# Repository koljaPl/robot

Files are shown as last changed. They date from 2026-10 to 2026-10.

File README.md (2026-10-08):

# robot - From Simulation to Reality: How does a robot learn?

## Implementierung und aktueller Stand

Die [vollständige Übergabe mit 19 Abschnitten](docs/HANDOFF.md) enthält recherchierte Teile, Preise/Links, mechanische Spezifikation, Verkabelung, vollständigen Code, Kalibrierung und Baufolge. [Prüfprotokoll](docs/VALIDATION.md), [CAD/Explosionszeichnung](cad/ASSEMBLY.md), [Druckanfrage](cad/QUOTE_REQUEST.md) und [Simulationsvideo](docs/validation/nominal.mp4) liegen ebenfalls bei.

**Hardware noch nicht zum Kauf freigegeben:** Der bekannte Betrag einschließlich Versand beträgt **90,32 €**. Für Druckteile, passende Hörner/Schrauben und einen ausreichend belastbaren Stromanschluss bleiben 9,68 €; diese Kosten sind noch unbekannt. Es wurde nichts bestellt oder an echter Hardware getestet. Das Modell und die Druckdateien sind vorläufig.

Die Simulation ist lauffähig: sechs Gelenke (Hüft-Pitch, Knie-Pitch, Knöchel-Roll je Bein), geschätzte Masse 208,4 g, 50-Hz-Steuerung und IMU-basierte Beobachtungen ohne erfundene Gelenkrückmeldung. Zwölf Tests bestanden. Ein PPO-Testlauf mit 10.240 Schritten und zehn Auswertungen zeigte 30 Sekunden Stehen, **keine alternierenden Schritte** und nur etwa 1–2 mm Vorwärtsbewegung. Das Gehziel ist noch nicht erreicht.

```bash
python3.12 -m venv .venv
source .venv/bin/activate
python -m pip install -r requirements.txt
python evaluate.py --episodes 1 --output runs/neutral
python train.py --steps 2048 --seed 0 --output runs/smoke
python evaluate.py --model runs/smoke/final_model.zip --episodes 5 --seed 1000
```

Ein geprüftes Testmodell liegt unter `docs/validation/smoke_checkpoint.zip`. Video:

```bash
MUJOCO_GL=egl python evaluate.py --model docs/validation/smoke_checkpoint.zip --episodes 1 --video --output runs/video
```

Die Hardware-Kommunikation ist als begrenztes Protokoll mit Watchdog/Arming und Pseudocode beschrieben; deploybare Firmware und automatische Hardware-Steuerung sind noch nicht implementiert.

## PPP-Woche: Robotik, ML und Simulation

## Thema
**Robotik, Machine Learning und Computersimulation**

**Leitfrage:**  
Wie kann ein Roboter eine Bewegung in einer Simulation lernen und das Gelernte danach auf einen echten Roboter übertragen?

## Teilthemen

**Kolja:**  
Reinforcement Learning – Wie kann ein Roboter durch Versuch und Irrtum lernen?

**Ilgar:**  
Sim-to-Real – Wie kann man eine in der Simulation gelernte Steuerung auf einen echten Roboter übertragen?

## Idee
Wir wählen verfügbare Bauteile, prüfen Preis und mechanischen Aufbau und bilden diesen Roboter in einer Physik-Simulation nach.
Dort soll er selbstständig lernen, sich vorwärts zu bewegen. Dafür bekommt er für gute Aktionen eine Belohnung (Reward).

Danach versuchen wir, das trainierte Modell auf einen echten Roboter zu übertragen.

Zusätzlich wollen wir testen, ob das Training besser funktioniert, wenn sich während des Trainings Dinge wie Reibung, Gewicht oder Motorstärke leicht verändern.

## Grober Plan

1. Aufgabe, verfügbare Teile und vollständigen Lieferpreis prüfen
2. Einen Motor, Stromversorgung, Controller und IMU testen und vermessen
3. Passende Druckteile bestätigen, Prototyp montieren und wiegen
4. Digitale Kopie aus diesen Messungen erstellen und prüfen
5. Reinforcement-Learning-Umgebung erstellen
6. erstes Modell trainieren
7. Training mit zufällig veränderten Bedingungen
8. Ergebnisse vergleichen
9. Modell auf echten Roboter übertragen
10. Simulation und Realität vergleichen
11. Präsentation und Dokumentation fertig machen

## Was wir messen wollen

- zurückgelegte Strecke
- Geschwindigkeit
- Anzahl der Stürze
- sichtbare Fußhebung und alternierende Schritte (Rutschen zählt nicht)
- eventuell Energieverbrauch
- Unterschied zwischen Simulation und echtem Roboter

## Aufgabenverteilung

**Kolja**
- Simulation
- Reinforcement Learning
- Training
- Auswertung der Trainingsdaten

**Ilgar**
- Aufbau des echten Roboters
- Elektronik und Motoren
- Kalibrierung
- Tests in der echten Welt

**Zusammen**
- Planung
- Sim-to-Real
- Experimente
- Vergleich der Ergebnisse
- Präsentation

## Technik

- Python
- MuJoCo
- Gymnasium
- Stable-Baselines3 / PPO
- Raspberry Pi Pico H, PCA9685 und MPU6050 für den echten Roboter

## Ziel

Am Ende wollen wir zeigen, wie ein Computer ohne vorprogrammierte Bewegungsabläufe selbst lernen kann und warum eine Simulation nie genau gleich wie die echte Welt ist.

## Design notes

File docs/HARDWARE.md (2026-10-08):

# Hardware interface and power — provisional, no tested firmware

The baseline is six Waveshare 15024 MG90S servos, Pico H, BerryBase 157066 PCA9685, Funduino MPU6050 module, and Mean Well GST40A05-P1J. Do not energize a complete robot until the connector, harness, servo current and fit gates in `procurement.json` pass. No purchases or hardware tests were performed.

## Power circuit

```mermaid
flowchart TD
  AC[Wall socket] --> Lead[Schuko–C13 lead]
  Lead --> PSU[Enclosed Mean Well 5 V / 5 A PSU]
  PSU --> Cut[Accessible 5 A rated DC disconnect — selection pending]
  Cut --> Bus[Short heavy copper positive and ground buses]
  Bus --> S[Six servo branches; bulk capacitor across bus]
  PC[Laptop USB-A] --> Pico[Pico H USB, logic only]
  Pico --> Logic[3.3 V PCA9685 logic and MPU6050]
  Pico --> PWM[PCA9685 six PWM signal outputs]
  PWM --> S
  Bus --> Ground[Single common ground connection to logic]
  Ground --> Pico
```

**Servo supply current bypasses the Pico, Dupont jumpers, breadboards, and the unverified PCA9685 power traces.** The selected PCA board generates pulses; it does not drive the motors electrically. Its chip's output-current specification concerns signals, not the servo V+ rail. [NXP datasheet](https://www.nxp.com/docs/en/data-sheet/PCA9685.pdf)

A helper prepares six 10 cm JR extensions as a power-injection harness. Keep the signal conductor connected between the male PCA-end connector and the female servo connector. Disconnect the power and return conductors from the PCA-end connector and join their **servo-side** ends to the positive and negative buses. Insulate all cut stubs and joints. Each servo still plugs into a replaceable extension. Add a short logic ground connection at the bus entry. Leave PCA V+ and its motor-power terminal unused. Verify continuity and connector polarity before any servo is attached. This wire preparation is part of the accepted helper job; the student assembles finished parts. The extensions' wire gauge and branch current rating remain unverified.

Use 0.75 mm² copper for buses no longer than 0.10 m each way. Resistance estimate at room temperature is `0.0175 × 0.20 / 0.75 = 0.0047 Ω`; 4.8 A would drop about 0.022 V there, **excluding PSU lead, connectors and individual servo leads**. A 2 m one-way tether of the same wire would drop about 0.45 V at 4.8 A and is unsuitable for a nominal 5 V rail. For the first 0.3 m trials use the PSU's existing lead, place the PSU near the floor test area, and route a slack loop with strain relief close to the torso COM. Several metres require a separately sourced thicker low-resistance cable and longer USB lead; these are not included in the certified-price subtotal.

Current assumptions, **not MG90S measurements**:

| State | Per servo hypothesis | Six-servo total |
|---|---:|---:|
| Loaded standing / slow movement average | 0.10–0.25 A | 0.6–1.5 A |
| Brief acceleration / near stall | 0.8 A | 4.8 A |

Pico, IMU and PWM logic draw from laptop USB, provisionally below 0.15 A combined. A 5 A PSU has only 0.2 A margin against the assumed six-servo peak. The selected servo has **no reliable product-specific current specification**: if measured transients exceed capacity, voltage drops below 4.8 V, or a connector becomes warm, stop and revise the budget/power design. A capacitor does not fix an undersized PSU. At 4.8 A, 1000 µF sustains only roughly 0.04 ms for a 0.2 V drop. It helps short transients, not sustained stalls.

Check loaded voltage at the farthest servo, including the factory PSU lead. The acceptable measured operating range is 4.8–6.0 V; do not assume a nominal 5 V label guarantees 4.8 V at every motor. Keep mains wiring entirely inside commercial leads and the enclosed PSU. [Selected PSU](https://www.berrybase.de/meanwell-schaltnetzteil-5v-dc-5-0a-mit-hohlstecker-5-5x2-1mm)

The required physical cutoff is an accessible **DC unplug connection rated for the full expected current**, near the operator. Its sourcing is still open. Disconnect it to remove servo power; the small downstream capacitor discharges briefly. A mains switch is a useful backup but has PSU hold-up delay. Disabling PWM or sending STOP cannot guarantee an analogue servo releases its last position, and is never equivalent to disconnecting power. Disarm before reconnecting servo power. No rail-voltage or per-servo current measurement is built in.

The €0.50 Goobay 76743 screw adaptor is a researched candidate with an **unknown current rating**, not a verified 5 A solution. The €1.80 BerryBase DCKSW cable is unavailable and also lacks a confirmed suitable DC rating. Neither is accepted to close the basket. [Adaptor](https://www.berrybase.de/dc-kupplung-fuer-hohlstecker-5-5x2-1mm-schraubmontage-terminal-block-2-pin), [switch cable](https://www.berrybase.de/dc-kabel-mit-schalter-5-5x2-1mm-stecker-5-5x2-1mm-buchse-35cm)

## Logic wiring

| Pico signal / physical pin | Connection |
|---|---|
| 3V3 OUT / 36 | PCA VCC and IMU VCC, both 3.3 V logic |
| GND / 38 | PCA GND, IMU GND and short connection to servo return bus |
| GP4 / 6 | I2C0 SDA, both boards |
| GP5 / 7 | I2C0 SCL, both boards |
| GP6 / 9 | PCA OE, 10 kΩ pull-up to 3.3 V |
| USB Micro B | USB data and Pico power |

The Pico never connects servo 5 V to VBUS, VSYS or 3V3. Use one short I2C bus at 400 kHz, PCA default address 0x40, IMU address 0x68 with AD0 grounded; scan first. Verify both modules' pull-ups go to **3.3 V**, not servo 5 V. Set MPU6050 ±16 g, ±2000°/s, approximately 44 Hz digital filtering and 200 Hz sample rate. Rotate the measured sensor axes into torso x-forward/y-left/z-up coordinates before passing samples to the shared estimator. [Pico pinout](https://datasheets.raspberrypi.com/pico/Pico-R3-A4-Pinout.pdf), [MPU6050 registers](https://invensense.tdk.com/wp-content/uploads/2015/02/MPU-6000-Register-Map1.pdf)

PCA channels 0–5: left hip, left knee, left ankle, right hip, right knee, right ankle. Set actual PWM frame frequency to 50 Hz and calibrate its oscillator; nominal PWM resolution is about 4.88 µs per tick. Configure OE-high outputs LOW. The board may have an onboard OE pull-down: remove/change it if necessary so the external pull-up actually disables outputs during Pico reset. Verify the power-up waveform before attaching horns. The selected servo's 3.3 V signal threshold is unknown and must pass a one-servo bench test. Do not assume every MG90S-labelled servo has identical electronics.

Helper soldering: any loose IMU/PCA headers, six signal output pins if not fitted, OE pull-up, capacitor and power-injection harness. A temperature-controlled iron, flux-core solder, cutters/stripper, heat-shrink and multimeter suffice. Borrow the school's equipment if possible; tools are excluded from the component budget. Solder/heat preparation happens away from attached servos and USB. No frame drilling, sawing, tapping or heat-set inserts are planned.

## Version 1 serial protocol

USB CDC, nominal serial baud 460800, ASCII newline packets, at most **192 bytes including newline**. No dynamically growing input buffer. Payload ends in `*HHHH\n`, CRC-16/CCITT with initial 0xFFFF (Python `binascii.crc_hqx`). SI units in Python; integer milliradians, millimetres/s² and milliradians/s on the wire. Use monotonic local timestamps modulo 2³² ms. USB baud is a descriptor setting, not the native CDC throughput limit.

| Payload before checksum | Purpose |
|---|---|
| `H,1,seq,pc_ms` | Hello/configuration query |
| `I,1,seq,mcu_ms,digest,cal_valid` | Hello response: lowercase 64-character SHA-256 digest and calibration validity 0/1 |
| `A,1,seq,pc_ms,1` | Explicit arm request |
| `A,1,seq,pc_ms,0` | Disarm request, always permitted |
| `C,1,seq,pc_ms,q0,q1,q2,q3,q4,q5` | Six validated target angles |
| `S,1,seq,pc_ms` | Stop: disable PWM and latch stop fault |
| `R,1,seq,pc_ms` | Clear faults only while disarmed and after their causes have been corrected; does not arm |
| `T,1,ack_seq,mcu_ms,status,q0,...,q5,ax,ay,az,gx,gy,gz` | Applied-target acknowledgement plus raw IMU sample, 200 Hz |

Status bit mask: 1 armed; 2 watchdog fault; 4 invalid command; 8 sensor/configuration fault; 16 stopped. Any fault is latched and disarms; rearming requires explicit fault clear after cause correction and a new handshake. Header sequence is uint16, time uint32; reject duplicates, stale packets and backward sequences with modulo comparison (`0 < delta < 32768`). More than 100 ms since a **valid fresh C command** disables PWM. Hello and telemetry do not refresh the command watchdog. PC monitors missing telemetry with its own 100 ms deadline. Neither clock is presumed synchronized. Use relative deltas and record receive times; handshake measures offset/round-trip latency.

Use one increasing PC sequence counter for all control packets. Only perform a new H handshake while disarmed. At H receipt, MCU records `pc_to_mcu_offset = mcu_receive_ms - pc_ms` modulo 2³². Convert later C timestamps with that offset, using signed wrap-safe differences; reject commands with inferred age above 80 ms or more than 20 ms in the future. PC checks handshake round-trip time is below 20 ms before requesting ARM. These provisional timing tolerances require bench measurement. A packet with a new sequence but old timestamp must not refresh the watchdog. Telemetry repeats the latest **applied C sequence**, so the PC permits repeated acknowledgements while independently requiring advancing MCU sample timestamps and rejecting duplicate/backward IMU samples.

`hardware_interface.py` implements bounded command encoding, CRC validation, telemetry parsing and per-servo calibrated pulse mapping. Command endpoints round inward to avoid quantized unsafe angles. `H/I/A/S/R` are protocol specifications, not implemented MCU handlers in this delivery. Digest is SHA-256 of the exact shared calibration/configuration file bytes agreed by PC and MCU; this file must include joint order, signs, angle limits, zero pulses, pulse gains, slew limit and IMU rotation/bias. Do not use the simulation-only XML hash as the hardware configuration digest. A receiver must validate exact packet kind, field count, integer range, CRC and version before any state change. Flush overlong input until newline, latch error, and keep outputs disabled. Never accept Python pickles, executable text, or unbounded JSON.

Applied targets describe the **post-validation, post-delay, post-rate-limiter commands** written to PWM. They are not measured shaft angles. Telemetry repeats the latest applied targets between 50 Hz updates. Do not label acknowledged angles “joint feedback.” Calibrate each channel's centre pulse, sign, µs/radian gain and safe pulse endpoints; there is no universal safe 500–2500 µs mapping.

## MCU and PC pseudocode

```text
BOOT:
  OE = HIGH; PWM outputs LOW; state = DISARMED
  load measured calibration; refuse ARM if absent or corrupt
  configure I2C, PCA 50 Hz, IMU 200 Hz; verify communication
  set applied targets to HOME but do not enable PWM

MAIN LOOP (nonblocking; hardware monotonic clock):
  parse bounded frames and CRC
  STOP/DISARM => OE HIGH; clear target queue; latch state as appropriate
  fresh valid COMMAND => check bounds; enqueue target; update watchdog
  ARM => only after explicit handshake, fresh HOME command, valid IMU,
         matching policy/configuration digest and cleared faults
  if armed and now - last_valid_command >= 100 ms:
      OE HIGH; state = WATCHDOG_FAULT; clear queue
  every 5 ms:
      read IMU; remove measured stationary biases; rotate into torso axes
      send timestamped T packet, applied targets, latest applied sequence, status
      sensor read failure/invalid sample => OE HIGH; latch fault
  every 20 ms if armed:
      accept pending command; apply measured command-delivery scheduling
      apply calibrated deadband and rate limit (initially <=3.6 degrees/tick)
      bound angles; map calibrated pulses; quantize to measured PCA ticks
      write six channels together; update applied targets/ack sequence

PC (initially hardware disconnected; no automatic ARM):
  load policy and matching physical/control/calibration configuration
  handshake, check version/order/calibration, initialize filter from rest IMU
  at each timestamped IMU sample:
      GravityEstimator.update(gyro, accel, measured_dt)
      check gyro/accel saturation, faults and freshness
  every 20 ms:
      frame = gravity(3), gyro/10(3), latest applied targets normalized(6),
              previous requested policy action(6)
      append to the same five-frame ObservationHistory
      policy predicts action; use action_to_target; send C frame
      remember requested action
  operator explicitly arms for a limited supervised trial
  fault, tilt >60 degrees, missing telemetry or Ctrl-C => send STOP;
      operator disconnects DC power and manually resets the robot
```

Initialize history with five copies of the measured resting frame, as in simulation. The simulator's initial 0.2 s settling interval does not replace a real startup check. Nominal command delay is a **provisional total PC-command to acknowledged-PWM delay** of 20 ms; at 50 Hz the random 20–40 ms delay often rounds to the next 40 ms tick. Do not add another guessed delay to the MCU until timings are measured. Servo shaft lag is represented separately by finite position-control dynamics. Timestamp comparisons need wrap handling and missed-tick rejection. This pseudocode requires implementation and electrical testing before hardware deployment.

Protect the USB lead and heavy power lead with a slack loop. Keep connector mass supported externally where possible. Cable force is not simulated, so record routing and direction in every physical trial. Never reset an RL episode by commanding an uncontrolled fallen robot back to HOME. Cut power, pick it up, inspect gears/brackets, then reinitialize.

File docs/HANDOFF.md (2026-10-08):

# School Biped S6 — hardware-first implementation handoff

Research checked 8 October 2026. Generated by `tools/build_handoff.py`; source files embedded below are the actual project files. **Status: runnable, locally tested simulation; provisional hardware design; procurement and manufacturing remain blocked.** Sourced claims, estimates, software results and unmeasured hardware are distinguished throughout.

## 1. Short design recommendation

Use six Waveshare 15024 MG90S servos in a small biped with **hip pitch, knee pitch and ankle roll on each leg**. Short 50 mm thighs/shins, broad 90 × 45 mm feet, laptop inference, Pico H, PCA9685 and an MPU6050 form a reasonable research baseline for slow stepping. Estimated assembled mass is **208.4 g**, with approximately **189 mm frame height** in the home pose. No arms or decorative head are required.

This is a prototype proposal, not a verified walking kit. The known delivered basket is **€90.32**, leaving **€9.68 for every unresolved item**. Finished prints, matched horns, fasteners and a suitably rated power connector are still unquoted/unconfirmed. The €100 constraint has **not** been met by a complete purchasable basket. Do not order the full robot or manufacture these interfaces yet. No component purchases or supplier messages were made.

The software can immediately run test training. Its provisional twin uses the proposed frame and exact selected product dimensions, plus explicitly estimated interfaces and dynamics. It is not a frozen twin of an assembled robot. A 10,240-step smoke run produced standing and approximately 1–2 mm of drift, **not walking**. The six-servo [Lynxmotion BRAT](https://wiki.lynxmotion.com/info/wiki/lynxmotion/view/ses-v1/ses-v1-robots/ses-v1-bipeds/brat/) is a mechanical precedent; it does not prove small-servo RL transfer.

## 2. Comparison of 6 DOF versus 8 DOF

| Design | Walking / stability | Cost, mass and power | RL / transfer / mechanics | Decision |
|---|---|---|---|---|
| A: each leg hip roll, hip pitch, knee pitch; 6 total | Lateral leg control, but both ankle axes fixed; foot orientation and landing constrained | Six servos €21, 73.2 g before frame; six unknown current loads | Few actions; fixed feet may require large lean and edge contact; easy frame, falls load hip gears | Compare only |
| B: A + ankle pitch; 8 total | Better sagittal foot alignment; no ankle roll; larger motion range | Servos €28, 97.6 g; **at least** €7 and 24.4 g extra plus brackets/wires/printing; assumed simultaneous peaks rise 4.8 → 6.4 A | More actions, failure points and calibration; extra freedom does not automatically help RL; proposed 5 A supply no longer covers the peak hypothesis | Upgrade requiring a new budget/power/frame design |
| Selected: hip pitch, knee pitch, ankle roll; 6 total | Direct lateral weight shift at the feet; broad soles help; coupled sagittal foot pitch limits step length | Six servos; same motor cost as A; short links reduce bending moments | Six controls and replaceable brackets; repeatable slow lean/lift/land sequence is plausible; no hip yaw or ankle pitch limits turning and uneven-ground performance | Baseline |

Eight joints cannot fit the present basket without further cost reductions: extra motors alone take the known subtotal to €97.32, before additional frame/power and the existing unknowns. Choose few joints to reduce calibration, wear and budget pressure. Neither configuration supplies true servo feedback or certified continuous torque. Stable walking remains an experiment.

## 3. Selected robot architecture

Joint order is **left hip, left knee, left ankle, right hip, right knee, right ankle**, everywhere. SI coordinates are **x forward, y left, z up**. Hips and knees rotate about local **+y**; ankle roll about **+x**. At zero angles, body axes match the parent. Positive pitch tips a downward link toward −x; positive ankle roll rotates the foot plane according to the right-hand rule. Physical right-hand servo mounting requires measured pulse signs; do not assume both legs share an electrical sign.

The torso contains the two hip servo housings, controller, PWM board and IMU. Each thigh carries its knee housing. Each shin carries no servo housing; each foot carries its ankle housing. This matches the proposed printed brackets and avoids double-counting actuator mass. Electronics are tied to the backplate with protected/insulated wiring; IMU mounting must be rigid. A short heavy power bus feeds servo branches separately from the logic.

The policy runs at **50 Hz** on the laptop. Pico processes the IMU at **200 Hz**, updates PCA pulse targets at 50 Hz and reports **post-limit command targets**, never measured shaft positions. MuJoCo runs at 500 Hz. A 200 Hz IMU on the 2 ms simulation grid alternates 4/6 ms intervals; the estimator uses the actual interval.

Actions are six normalized values in `[-1,1]`, mapped linearly to the JSON safe intervals. Home angles are `[-10,10,0,-10,10,0]°`; neutral action is therefore **not six zeros**. Each observation frame is estimated gravity direction (3), gyro divided by 10 rad/s (3), normalized applied command targets (6), previous requested actions (6). Five frames make **90 float32 observations**. The same complementary gravity filter uses raw accelerometer/gyro in simulation and the robot. Sensor axes/bias are calibrated before filtering; accelerometer blending is suppressed for large deviations from gravity. Translation, true attitude, true joint angles, velocity and contact are excluded from policy inputs. Five frames give roughly 80 ms of history; they cannot recover every unobserved servo error.

## 4. Servo comparison

These are product-specific claims, not interchangeable specifications for all similarly named servos. Prices include VAT; stock and variants must be checked at checkout. 1 kgf·cm = 0.09807 N·m.

| Exact product / source | Unit price / availability | Size; mass | Voltage; claimed stall torque | Claimed unloaded speed | Gear/control / assessment |
|---|---|---|---|---|---|
| [Waveshare 15286 SG90](https://www.welectron.com/Waveshare-15286-SG90-Servo_1) | €1.90; listing indicated about three months delivery | 22.8 × 12.2 × 28.5 mm; 10.5 g | 4.8–6 V; 2.0/2.2 kgf·cm | 0.09/0.08 s per 60° at 4.8/6 V | Plastic gears, position PWM; lower cost but gearbox/fall durability concerns; €9.60 saving for six does not establish the whole budget |
| **[Waveshare 15024 MG90S](https://www.welectron.com/Waveshare-15024-MG90S-Servo_1)** | **€3.50; shown in stock** | **22.8 × 12.2 × 28.5 mm; 12.2 g** | **4.8–6 V; 2.0/2.8 kgf·cm** | **0.11/0.09 s per 60° at 4.8/6 V** | Metal gears, position PWM; chosen for low price and replaceability, with selected-product dimensions |
| [MG90D at Rotorama](https://www.rotorama.de/product/mg90d) | €4.09; stock shown | 22.8 × 12.4 × 28.5 mm; 12 g | 4.8–6 V; 1.8/2.2 kgf·cm | Table says 0.10 and 0.08 s, both labelled 4.8 V; higher-voltage speed **unresolved** | Metal, digital position PWM; claimed 90° between 1000–2000 µs, horns included; not enough evidence of better repeatability to justify selecting it |
| [FEETECH FS90, Pololu data](https://www.pololu.com/product/2818/specs), [EU seller](https://eckstein-shop.de/feetech-fs90-1-5kg-analog-servo) | EU listing €3.55; availability/country messages ambiguous | 23.2 × 12.5 × 22 mm; 9 g | 4.8–6 V; 1.3/1.5 kgf·cm | 0.12/0.10 s per 60° | Plastic, analog PWM; 120° at 900–2100 µs, documented 3.3 V signals; weaker and different frame; **FS90R is continuous rotation and unsuitable** |

Selected listing also claims 180° travel and 5 µs deadband. Neither proves calibrated angular range, backlash or long-term repeatability. [Original TowerPro MG90S](https://towerpro.com.tw/product/mg90s-3/) has different mass/torque claims; those are not specifications for the Waveshare item. Very cheap servos can vary with load, voltage, temperature and wear. Metal gears do not guarantee low backlash. Expect per-servo calibration and replacements.

For all four, sustainable torque, lifetime and gear backlash are **unknown**. Current for the selected MG90S, SG90 and listed MG90D is **unknown**. Pololu measured approximately 600 mA stall and 200 mA no-load at 6 V for FS90, explicitly variable; its [manufacturer PDF](https://www.pololu.com/file/0J1435/FS90-specs.pdf) gives different current numbers. Do not transfer either current value to MG90S. No real torque/current measurements were performed.

Torque feasibility: `τ = m g d`. A 250 g mass at 20 mm offset requires `0.250 × 9.81 × 0.020 = 0.0491 N·m`; a rough 2× dynamic margin gives 0.0981 N·m. The selected seller's 4.8 V stall claim is 0.196 N·m. Stall torque is not a safe repeated-hold rating. The simulation starts with **0.08 N·m intermittent estimated force cap**; physical PWM servos have no programmable torque cap.

The actual 208.4 g proposed body distribution was evaluated by virtual work, holding the left foot fixed and allowing the right foot to be unloaded. Moments below are absolute magnitudes; this is a gravity calculation, not a loaded-servo test:

| Pose | Left hip | Left knee | Left ankle | 2× worst demand | Interpretation |
|---|---:|---:|---:|---:|---|
| Home, pretend single left support | 0.0013 | 0.0139 | 0.0695 N·m | 0.1390 N·m | COM is 34 mm to the side, outside 22.5 mm foot half-width; **not a feasible balanced single-support pose** |
| 15° lateral lean toward left | 0.0013 | 0.0134 | 0.0356 N·m | 0.0712 N·m | COM lateral offset 17.4 mm is inside the ideal support footprint; little measured margin yet |
| Lift right leg after leaning | 0.0039 | 0.0161 | 0.0337 N·m | 0.0675 N·m | Right knee gravity demand 0.0126 N·m; plausible slow-step starting pose |
| Deep stance bend, stress case | 0.0112 | 0.0494 | 0.0423 N·m | 0.0989 N·m | Exceeds provisional 0.08 N·m at 2× margin; do not treat every angle-limit pose as a safe loaded stance |

See [reproducible torque calculations](validation/torque_estimates.json) and `tools/torque_estimates.py`. Transfer weight before lifting; keep initial movements slow. Shock loads from falls are not covered by this static calculation.

## 5. Complete BOM with sourced prices and links

This is the complete **required-item register**, with unresolved costs explicitly retained. It is **not a complete purchasable basket**. Prices are checked listings, not saved checkout invoices. VAT and standard Germany shipping are included where priced. A free school helper is assumed for soldering/lead preparation; a paid charge must enter the budget. Laptop, measurement tools and ordinary screwdrivers are outside robot-part cost. No printer or battery is assumed.

| Category | Exact item / supplier source | Qty | Unit € | Line € | Selection / unresolved issue |
|---|---|---:|---:|---:|---|
| Motors | [Waveshare 15024 MG90S](https://www.welectron.com/Waveshare-15024-MG90S-Servo_1) — Welectron | 6 | 3.50 | 21.00 | VAT included, stock shown; horn/screw inclusion unverified |
| Electronics | [Raspberry Pi Pico H](https://www.berrybase.de/raspberry-pi-pico-rp2040-mikrocontroller-board-mit-headern) — BerryBase | 1 | 5.50 | 5.50 | Pre-soldered headers; USB Micro B |
| Electronics | [BerryBase 157066 PCA9685 board](https://www.berrybase.de/berrybase-16-kanal-pwm-servo-treiber-board-pca9685-i2c-12bit-1-6khz-3-3-5v) — BerryBase | 1 | 6.50 | 6.50 | One in stock; loose connectors in package. Use only signals/logic: power rail rating unknown |
| Sensors | [Funduino F23107397 MPU6050 module](https://funduinoshop.com/elektronische-module/sensoren/bewegungs-und-distanzsensoren/mpu-6050-modul-triaxial-beschleunigungssensor-gyroskop) — Funduino | 1 | 2.90 | 2.90 | Header soldering/board orientation to confirm |
| Power | [Mean Well GST40A05-P1J 5 V 5 A desktop PSU](https://www.berrybase.de/meanwell-schaltnetzteil-5v-dc-5-0a-mit-hohlstecker-5-5x2-1mm) — BerryBase | 1 | 14.90 | 14.90 | C14 inlet; centre-positive 5.5 x 2.1 mm; no mains lead in package |
| Power | [Goobay 68604 Schuko to C13, 1.5 m](https://www.berrybase.de/kaltgeraete-netzkabel-schutzkontakt-stecker-abgewinkelt-iec320-c13-buchse-schwarz) — BerryBase | 1 | 3.81 | 3.81 | Exact 1.5 m variant; 10 A AC rating |
| Wiring/connectors | [Official Raspberry Pi RPI-MUSB-1 USB data cable 1 m](https://www.berrybase.de/offizielles-raspberry-pi-micro-usb-kabel-rot-1-0m) — BerryBase | 1 | 1.80 | 1.80 | USB-A PC assumed; USB-C-only PC requires extra adapter, currently not priced |
| Wiring/connectors | [DUPK-40-FF-20, 40 female-female Dupont leads, 20 cm](https://www.berrybase.de/40pin-jumper-dupont-kabel-female-female-trennbar/laenge-0-20-m) — BerryBase | 1 | 1.80 | 1.80 | Logic/IMU only, AWG28; never main servo power |
| Wiring/connectors | [Funduino F23108007 JR-Futaba extension, 10 cm](https://funduinoshop.com/elektronische-module/elektromotoren-und-zubehoer/elektromotoren/servomotoren/jr-futaba-servo-verlaengerung-kabel-10cm-female/male) — Funduino | 6 | 1.42 | 8.52 | Helper prepares power-injection harness; branch current rating/gauge unverified |
| Wiring/connectors | [Donau E-175-16 violet copper wire 0.75 mm², 10 m roll](https://www.berrybase.de/donau-kupferschaltlitze-0-75-mm2-10m-lang-1-adrig-24x0-20mm-pvc-isoliert) — BerryBase | 1 | 5.50 | 5.50 | Only short power buses, <=10 cm each way; label positive/negative with shrink sleeve. Not a long tether |
| Power | [AiSHi ELK1M16VAWH 1000 µF 16 V capacitor](https://www.berrybase.de/elektrolytkondensator-1000-f-16v-1050c-1-radial-tht) — BerryBase | 1 | 0.29 | 0.29 | Polarity matters; actual tolerance ±20%, inconsistent page title ignored |
| Electronics | [MSW10K.25 10 kOhm axial resistor](https://www.berrybase.de/bauelemente/passive-bauelemente/widerstaende/) — BerryBase | 1 | 0.05 | 0.05 | OE pull-up; SKU price verified on category; exact detail URL not resolved |
| Wiring/connectors | [PINH-1X40P 40-pin 2.54 mm header](https://www.berrybase.de/stiftleiste-1x-40-polig-rm-2-54-gerade) — BerryBase | 1 | 0.60 | 0.60 | Helper cuts/solders signal and sensor headers as needed; Pico headers already fitted |
| Wiring/connectors | [McPower T1535561 heat-shrink, 100 pieces](https://www.berrybase.de/schrumpfschlauch-set-100-teilig-schwarz) — BerryBase | 1 | 1.90 | 1.90 | Insulate helper-soldered harness; mark polarity; helper supplies solder as workshop consumable |
| Fasteners | [McPower T1535501 cable ties, 100 x 2.5 mm, pack of 100](https://www.berrybase.de/kabelbinder-uv-bestaendig-nylon-100-stueck/farbe-transparent/masse-100x2-5mm) — BerryBase | 1 | 0.45 | 0.45 | 8 board mounts, 4 cable strain relief, 8 harness restraints; keep away from pinch points |
| Mechanical | [7 ready-finished PETG frames + 2 bonded TPU soles, VAT and German shipping](https://meltlab.de/preise) — Print service, quote pending | 1 | **pending** | **pending** | Exact STL upload quote unavailable; no printer/browser surface available. Not a price allowance |
| Mechanical | [6 matching horns + 6 servo shaft retaining screws](https://www.welectron.com/Waveshare-15024-MG90S-Servo_1) — Selected servo supplier; package confirmation pending | 1 | **pending** | **pending** | Required. Do not assume included; exact spline/horn pattern/shaft screw thread unknown |
| Fasteners | 12 M2 x 8 mm ear screws, 12 M2 nuts, 24 M2 washers; 12 horn-to-frame screws/washers matched to supplied horns — Print-service assembly kit quote pending | 1 | **pending** | **pending** | Dimensions/lengths provisional; supplier must include a matching kit and factory-clear holes. No drilling/tapping by assembler |
| Power | 5 A rated DC female 5.5 x 2.1 mm input pigtail/coupler and accessible disconnect, strain relief — Not selected: current-rated connector still unresolved | 1 | **pending** | **pending** | Goobay 76743 €0.50 not accepted as 5 A rated; rating unknown. Required input connection cannot be omitted |
| Shipping | [Welectron German DPD shipping](https://www.welectron.com/Shipping-cost) — Welectron | 1 | 4.95 | 4.95 | Basket under €49 free-shipping threshold |
| Shipping | [BerryBase German DHL shipping](https://www.berrybase.de/versand-und-zahlungsbedingungen) — BerryBase | 1 | 4.95 | 4.95 | Basket under €150 free-shipping threshold |
| Shipping | [Funduino German shipping](https://funduinoshop.com/versand-und-zahlungsbedingungen) — Funduino | 1 | 4.90 | 4.90 | One combined sensor/extensions order; separate first-servo order would add another shipping charge |

Selection rationale and alternatives: Pico H avoids header soldering and unnecessary Wi-Fi; a bare Pico might save board cost but adds soldering and needs a fresh price check. PCA9685 gives a common 50 Hz pulse source; Pico has enough PWM channels to replace it, but that changes this baseline and the firmware. MPU6050 is an inexpensive useful attitude/gyro source; no camera, lidar, encoder or foot switch is required. An IMU is strongly recommended because a command-only controller cannot detect body tipping. The enclosed Mean Well PSU avoids exposed mains wiring; a generic cheaper adapter is not accepted without a credible voltage/current rating and compliance documentation. Pre-soldered IMU/PWM alternatives could reduce helper work, but their delivered prices have not been established. Wires, resistor, header, capacitor, ties and shrink sleeve provide the required harness/OE/mounting functions; borrowing spare workshop parts changes actual cost only when confirmed.

The selected PCA board package lists loose connectors, so helper assembly is included as work, not assumed already soldered. Servo branches use six extensions prepared by the helper for power injection; branch gauge/current capability must be checked. No rail rating is assumed for PCA traces. Horn/screw inclusion is **not verified** and remains a required pending item.

Optional items: one spare MG90S costs €3.50 before any extra delivery; a slack safety line, thin protective mat and longer USB/heavier power tether remain unpriced optional additions. A USB-C-only laptop requires an adapter, which would become required. The baseline PSU lead/USB cable are approximately 1 m: initial short steps are possible near the supply, but a few-metre travel setup needs a separately priced tether. No complex overhead rig is mandatory.

## 6. Total cost and budget gate

| Budget element | Cost |
|---|---:|
| Known required products | **€75.52** |
| Welectron + BerryBase + Funduino standard shipping | **€14.80** |
| Known delivered subtotal | **€90.32** |
| Finished printing/soles, matched horn hardware, fasteners, rated DC connection | **Unknown** |
| Complete delivered total | **Not established** |
| Remaining under €100 for every unknown | **€9.68** |

The €50–75 target is not achieved by this basket: known products alone exceed €75, before shipping and all pending items. There is **no verified cheapest viable delivered configuration** under €100. The recommended configuration above is conditional on a passing quote and fit gate. An explicitly revised direct-Pico-PWM design could remove the €6.50 PCA board, bringing this known subtotal to €83.82 if all other costs stayed equal; printing/hardware remain unknown, so this is not a purchasable alternative or a silent substitution. Weaker servos have not been selected to disguise a shortfall.

If pending delivered costs sum to `U`, complete cost is `90.32 + U`; actual shortfall is `max(0, U − 9.68)`. No numeric shortfall can be truthfully reported before the quote. `tools/budget_gate.py` treats unpriced parts as pending, never zero; it exits 2 for incomplete, 1 for over budget and 0 only for a fully cleared basket. See [current machine-readable gate](budget_status.json).

The [Meltlab price/quotation page](https://meltlab.de/preise) and [Printfaktur](https://printfaktur.de/) provide quote routes. An exact quote was not obtained: no browser/upload surface is available in this environment, and no supplier was contacted. [Ready-to-review quotation brief](../cad/QUOTE_REQUEST.md) and [quote bundle](../cad/quote_bundle.zip) include exact prototype files. A headline per-part printing price or an allowance is not a quotation. Resolve horn/ear fit before sending a manufacturing order. If the delivered quote breaks €100, stop procurement and revise explicitly.

## 7. Mechanical design and assembly

`physical_spec.json` is the authoritative physical ledger. `build_model.py` mirrors right-side components and computes aggregate mass/COM/full inertia, assigning each servo, frame, PCB, fastener allowance and wire allowance **exactly once**. Rigid-body inertias are solid CAD estimates for PETG frames and uniform-box estimates for other components, combined using the parallel-axis theorem. They are not measured inertias. The hanging tether is excluded; its disturbance must later be measured.

| Body | Parent | Joint / axis | Origin in parent (mm) | Limits (°) | Mass (g) | COM local (mm) |
|---|---|---|---|---|---:|---|
| torso | world | root / floating | 0.000, 0.000, 154.240 | free | 81.89 | -7.350, 0.000, -8.997 |
| left_thigh | torso | left_hip / 0.000, 1.000, 0.000 | 0.000, 34.000, -30.000 | [-35, 35] | 18.97 | 0.000, -9.434, -42.970 |
| left_shin | left_thigh | left_knee / 0.000, 1.000, 0.000 | 0.000, 0.000, -50.000 | [-10, 60] | 7.72 | 1.432, 1.714, -22.688 |
| left_foot | left_shin | left_ankle / 1.000, 0.000, 0.000 | 0.000, 0.000, -50.000 | [-20, 20] | 36.58 | -1.919, 0.000, -15.367 |
| right_thigh | torso | right_hip / 0.000, 1.000, 0.000 | 0.000, -34.000, -30.000 | [-35, 35] | 18.97 | 0.000, 9.434, -42.970 |
| right_shin | right_thigh | right_knee / 0.000, 1.000, 0.000 | 0.000, 0.000, -50.000 | [-10, 60] | 7.72 | 1.432, -1.714, -22.688 |
| right_foot | right_shin | right_ankle / 1.000, 0.000, 0.000 | 0.000, 0.000, -50.000 | [-20, 20] | 36.58 | -1.919, -0.000, -15.367 |

Torso envelope is 40 × 82 × 66 mm. Each inter-joint leg segment is 50 mm. Feet are 90 × 45 × 3 mm PETG plus 1 mm TPU, local centre x = +6 mm, z = −22.5 mm for the plate and −24.5 mm for the sole. Ankle-to-floor distance is 25 mm when flat. Servo dimensions refer to the seller's overall case envelope; shaft, ears, spline, horn holes and lead exit are **unmeasured**. These unresolved features prevent manufacturing release.

| Body | Component (mass assigned once) | Dimensions xyz (mm) | Mass (g) | COM local xyz (mm) |
|---|---|---|---:|---|
| torso | torso_frame | 32.000, 82.000, 88.750 | 21.49 | -16.308, -0.000, -5.438 |
| torso | pico_h | 6.000, 51.000, 21.000 | 4.00 | -14.500, 0.000, 23.000 |
| torso | pca9685 | 9.000, 62.500, 25.400 | 9.00 | -13.000, 0.000, -2.000 |
| torso | imu | 4.000, 16.000, 20.000 | 3.00 | -25.500, 0.000, 18.000 |
| torso | torso_wires_fasteners | 30.000, 70.000, 40.000 | 20.00 | 0.000, 0.000, 5.000 |
| torso | left_hip_servo | 12.200, 28.500, 22.800 | 12.20 | 0.000, 19.750, -34.750 |
| torso | right_hip_servo | 12.200, 28.500, 22.800 | 12.20 | 0.000, -19.750, -34.750 |
| left_thigh | left_thigh_frame | 24.000, 13.500, 87.750 | 5.27 | 0.000, -0.974, -24.526 |
| left_thigh | left_knee_servo | 12.200, 28.500, 22.800 | 12.20 | 0.000, -14.250, -54.750 |
| left_thigh | left_thigh_joint_fasteners | 20.000, 12.000, 12.000 | 1.50 | 0.000, 0.000, -12.000 |
| left_shin | left_shin_frame | 24.000, 24.000, 78.000 | 6.22 | 1.777, 2.128, -25.264 |
| left_shin | left_shin_joint_fasteners | 20.000, 12.000, 12.000 | 1.50 | 0.000, 0.000, -12.000 |
| left_foot | left_foot_frame | 90.000, 45.000, 38.250 | 18.02 | 4.134, 0.000, -20.373 |
| left_foot | left_sole | 90.000, 45.000, 1.000 | 4.86 | 6.000, 0.000, -24.500 |
| left_foot | left_ankle_servo | 28.500, 12.200, 22.800 | 12.20 | -14.250, 0.000, -4.750 |
| left_foot | left_foot_joint_fasteners | 20.000, 12.000, 12.000 | 1.50 | 0.000, 0.000, -12.000 |
| right_thigh | right_thigh_frame | 24.000, 13.500, 87.750 | 5.27 | 0.000, 0.974, -24.526 |
| right_thigh | right_knee_servo | 12.200, 28.500, 22.800 | 12.20 | 0.000, 14.250, -54.750 |
| right_thigh | right_thigh_joint_fasteners | 20.000, 12.000, 12.000 | 1.50 | 0.000, 0.000, -12.000 |
| right_shin | right_shin_frame | 24.000, 24.000, 78.000 | 6.22 | 1.777, -2.128, -25.264 |
| right_shin | right_shin_joint_fasteners | 20.000, 12.000, 12.000 | 1.50 | 0.000, 0.000, -12.000 |
| right_foot | right_foot_frame | 90.000, 45.000, 38.250 | 18.02 | 4.134, -0.000, -20.373 |
| right_foot | right_sole | 90.000, 45.000, 1.000 | 4.86 | 6.000, 0.000, -24.500 |
| right_foot | right_ankle_servo | 28.500, 12.200, 22.800 | 12.20 | -14.250, 0.000, -4.750 |
| right_foot | right_foot_joint_fasteners | 20.000, 12.000, 12.000 | 1.50 | 0.000, 0.000, -12.000 |

Component dimensions are approximate envelopes, not every detailed printed surface. Frames use solid PETG density 1270 kg/m³, TPU estimate 1200 kg/m³. Actual infill and finished printing change mass. Fastener/wire masses are estimates; servo mass is a seller claim. Aggregate full inertias are:

| Body | Ixx, Iyy, Izz, Ixy, Ixz, Iyz (kg·m²) |
|---|---|
| torso | 8.105528e-05, 5.228549e-05, 4.646465e-05, 2.541099e-21, 8.152129e-06, 0 |
| left_thigh | 1.075608e-05, 9.509007e-06, 2.306097e-06, -1.321365e-23, 9.846622e-24, -2.552041e-06 |
| left_shin | 3.771568e-06, 3.870593e-06, 4.366762e-07, 1.069363e-08, 2.608766e-07, -1.717284e-07 |
| left_foot | 7.376615e-06, 2.141873e-05, 2.153521e-05, -9.25926e-23, 2.911645e-06, 1.500083e-22 |
| right_thigh | 1.075608e-05, 9.509007e-06, 2.306097e-06, 1.321365e-23, 9.846622e-24, 2.552041e-06 |
| right_shin | 3.771568e-06, 3.870593e-06, 4.366762e-07, -1.069363e-08, 2.608766e-07, 1.717284e-07 |
| right_foot | 7.376615e-06, 2.141873e-05, 2.153521e-05, 9.25926e-23, 2.911645e-06, -1.500083e-22 |

Editable CAD is [cad/build_frame.py](../cad/build_frame.py), producing seven named frame STLs and two sole STLs in `cad/stl/`. All nine meshes are watertight and each frame is one connected solid. `quotation_plate.stl` is a convenience visualization of the seven frames; **do not order it in addition to those frames**. No external proprietary CAD program is needed to edit the Python dimensions. [Exploded view](../cad/exploded.png) shows assembly relationships. [Assembly instructions and fastener counts](../cad/ASSEMBLY.md) cover six joints and electronics mounting.

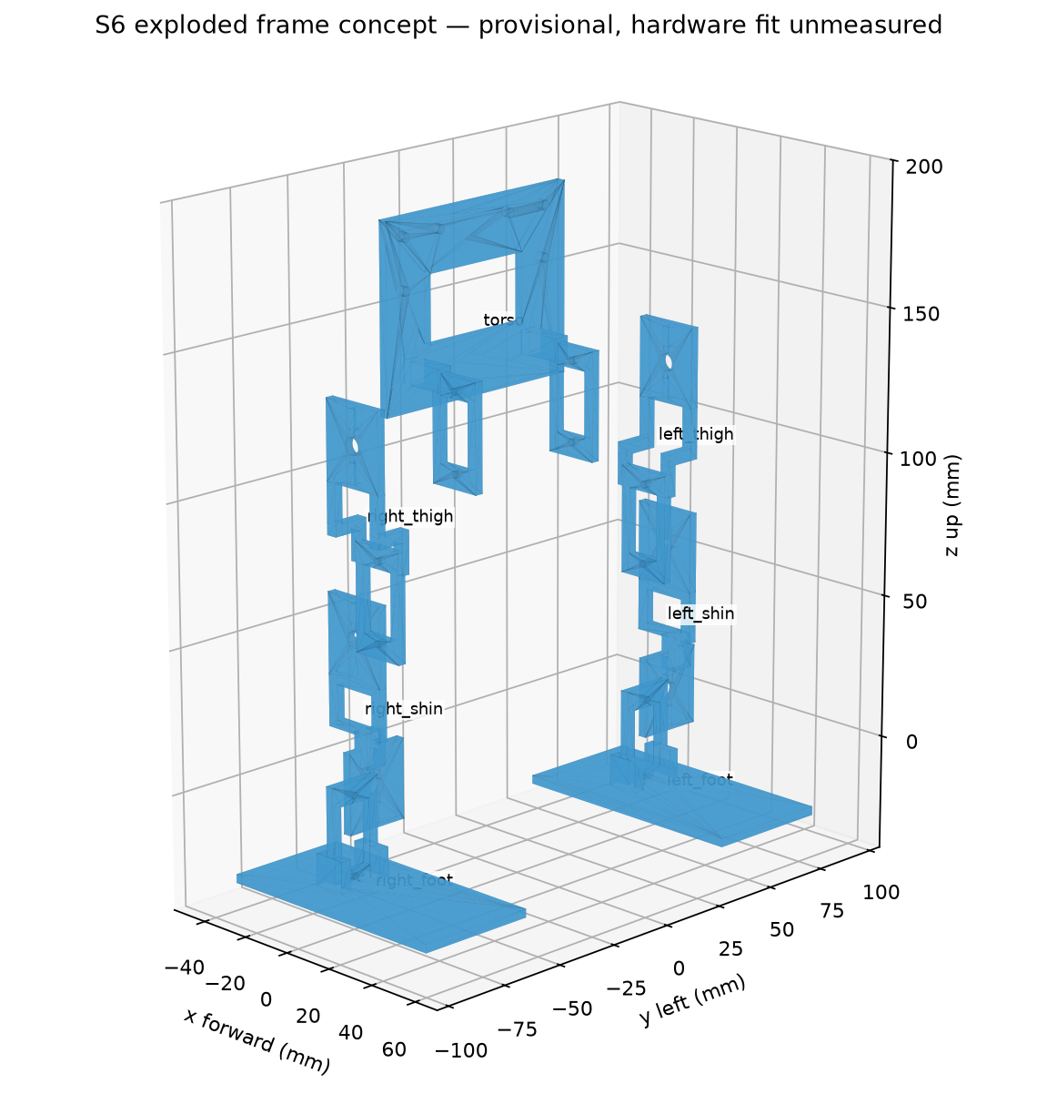
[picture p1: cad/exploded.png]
Exploded prototype frame; interface fit is not manufacturing-approved


Prepared parts must arrive with usable holes and no cutting/drilling/tapping/heat-set inserts. Provisional quantities are 12 M2 × 8 ear screws, 12 nuts, 24 washers, 12 matched horn-to-frame screws/washers, six horn shaft screws and six horns. Exact horn screw thread and mounting lengths must be confirmed with the actual package. The service must include any sole bonding/finishing; its price is pending. Printed walls are nominally 3 mm; preferred PETG frame and compliant replaceable TPU soles. A finite mesh audit checked 55 poses for frame/frame and assigned-case/frame intersections; it does not certify horn fit, cable clearance, strength, all continuous poses or every neighboring component.

The full physical ledger is included here so copying the runnable sources also supplies their required JSON:

```json
{
  "name": "School Biped S6",
  "status": "PROVISIONAL: budget, printed fit and hardware calibration not approved",
  "units": "m, kg, rad, s",
  "coordinates": "x forward, y left, z up; local body axes match parent at zero joint angle",
  "home_joint_angles_deg": [-10, 10, 0, -10, 10, 0],
  "servo": {
    "model": "Waveshare 15024 MG90S",
    "mass": 0.0122,
    "housing_dimensions": [
      0.0228,
      0.0122,
      0.0285
    ],
    "shaft_offset_along_case_length": 0.00475,
    "shaft_to_case_center_axial": 0.01425,
    "mounting_hole_spacing": 0.028,
    "mounting_hole_diameter": 0.0022,
    "status": "housing size and mass are seller claims; shaft/ear/horn dimensions are estimates requiring measurement"
  },
  "geometry": {
    "hip_half_spacing": 0.034,
    "hip_z": -0.03,
    "thigh_length": 0.05,
    "shin_length": 0.05,
    "foot_dimensions": [
      0.09,
      0.045,
      0.003
    ],
    "foot_center": [
      0.006,
      0,
      -0.0225
    ],
    "sole_thickness": 0.001,
    "ankle_to_floor": 0.025,
    "torso_dimensions": [
      0.04,
      0.082,
      0.066
    ]
  },
  "bodies": [
    {
      "name": "torso",
      "parent": "world",
      "position": [
        0,
        0,
        0.154240388
      ],
      "joint": "root",
      "axis": null,
      "limits_deg": null,
      "components": [
        {
          "name": "torso_frame",
          "mass": 0.021486247742229223,
          "dimensions": [
            0.032,
            0.082,
            0.08875
          ],
          "com": [
            -0.016308210070435095,
            -5.215214943911107e-19,
            -0.0054384916759348196
          ],
          "inertia_tensor": [
            [
              2.6309016723560255e-05,
              2.703988807846125e-21,
              2.1653112995251776e-06
            ],
            [
              2.703988807846125e-21,
              1.3253368557151762e-05,
              3.4107973696966715e-22
            ],
            [
              2.1653112995251776e-06,
              3.4107973696966715e-22,
              1.578588698727872e-05
            ]
          ],
          "material": "solid PETG estimate, 1270 kg/m\u00b3",
          "evidence": "generated CAD; actual infill/printed density must be weighed"
        },
        {
          "name": "pico_h",
          "mass": 0.004,
          "dimensions": [
            0.006,
            0.051,
            0.021
          ],
          "com": [
            -0.0145,
            0,
            0.023
          ],
          "material": "PCB and headers",
          "evidence": "estimate"
        },
        {
          "name": "pca9685",
          "mass": 0.009,
          "dimensions": [
            0.009,
            0.0625,
            0.0254
          ],
          "com": [
            -0.013,
            0,
            -0.002
          ],
          "material": "PCB and connectors",
          "evidence": "seller claim mass; height estimate"
        },
        {
          "name": "imu",
          "mass": 0.003,
          "dimensions": [
            0.004,
            0.016,
            0.02
          ],
          "com": [
            -0.0255,
            0,
            0.018
          ],
          "material": "PCB",
          "evidence": "estimate"
        },
        {
          "name": "torso_wires_fasteners",
          "mass": 0.02,
          "dimensions": [
            0.03,
            0.07,
            0.04
          ],
          "com": [
            0,
            0,
            0.005
          ],
          "material": "copper, plastic, steel",
          "evidence": "estimate includes six added 10 cm extensions, short heavy power wire, capacitor, pullup, board mounting ties and torso hardware; excludes suspended tether"
        },
        {
          "name": "left_hip_servo",
          "mass": 0.0122,
          "dimensions": [
            0.0122,
            0.0285,
            0.0228
          ],
          "com": [
            0,
            0.01975,
            -0.03475
          ],
          "material": "servo composite",
          "evidence": "seller mass, estimated uniform inertia"
        },
        {
          "name": "right_hip_servo",
          "mass": 0.0122,
          "dimensions": [
            0.0122,
            0.0285,
            0.0228
          ],
          "com": [
            0,
            -0.01975,
            -0.03475
          ],
          "material": "servo composite",
          "evidence": "seller mass, estimated uniform inertia"
        }
      ]
    },
    {
      "name": "left_thigh",
      "parent": "torso",
      "position": [
        0,
        0.034,
        -0.03
      ],
      "joint": "left_hip",
      "axis": [
        0,
        1,
        0
      ],
      "limits_deg": [
        -35,
        35
      ],
      "components": [
        {
          "name": "left_thigh_frame",
          "mass": 0.005273029560391083,
          "dimensions": [
            0.024,
            0.013500000000000002,
            0.08775
          ],
          "com": [
            2.6563334945902374e-19,
            -0.0009738150793376264,
            -0.02452563897898925
          ],
          "inertia_tensor": [
            [
              3.6463630740464687e-06,
              -1.3640154818355183e-24,
              3.5681746524361245e-23
            ],
            [
              -1.3640154818355183e-24,
              3.83564073707392e-06,
              -5.988303056018393e-07
            ],
            [
              3.5681746524361245e-23,
              -5.988303056018393e-07,
              4.6710755114091395e-07
            ]
          ],
          "material": "solid PETG estimate, 1270 kg/m\u00b3",
          "evidence": "generated CAD; actual infill/printed density must be weighed"
        },
        {
          "name": "left_knee_servo",
          "mass": 0.0122,
          "dimensions": [
            0.0122,
            0.0285,
            0.0228
          ],
          "com": [
            0,
            -0.01425,
            -0.05475
          ],
          "material": "servo composite",
          "evidence": "seller mass, estimated inertia"
        },
        {
          "name": "left_thigh_joint_fasteners",
          "mass": 0.0015,
          "dimensions": [
            0.02,
            0.012,
            0.012
          ],
          "com": [
            0,
            0,
            -0.012
          ],
          "material": "steel and plastic horns",
          "evidence": "estimate; weigh installed fasteners/horn"
        }
      ]
    },
    {
      "name": "left_shin",
      "parent": "left_thigh",
      "position": [
        0,
        0,
        -0.05
      ],
      "joint": "left_knee",
      "axis": [
        0,
        1,
        0
      ],
      "limits_deg": [
        -10,
        60
      ],
      "components": [
        {
          "name": "left_shin_frame",
          "mass": 0.006223103503190493,
          "dimensions": [
            0.024,
            0.024,
            0.078
          ],
          "com": [
            0.001777148714462294,
            0.002127532309995988,
            -0.025264417900762635
          ],
          "inertia_tensor": [
            [
              3.517439052233832e-06,
              1.526352745623322e-08,
              2.3238492246555624e-07
            ],
            [
              1.526352745623322e-08,
              3.5861170810492066e-06,
              -2.0583750953748297e-07
            ],
            [
              2.3238492246555624e-07,
              -2.0583750953748297e-07,
              3.5938805714611084e-07
            ]
          ],
          "material": "solid PETG estimate, 1270 kg/m\u00b3",
          "evidence": "generated CAD; actual infill/printed density must be weighed"
        },
        {
          "name": "left_shin_joint_fasteners",
          "mass": 0.0015,
          "dimensions": [
            0.02,
            0.012,
            0.012
          ],
          "com": [
            0,
            0,
            -0.012
          ],
          "material": "steel and plastic horns",
          "evidence": "estimate; weigh installed fasteners/horn"
        }
      ]
    },
    {
      "name": "left_foot",
      "parent": "left_shin",
      "position": [
        0,
        0,
        -0.05
      ],
      "joint": "left_ankle",
      "axis": [
        1,
        0,
        0
      ],
      "limits_deg": [
        -20,
        20
      ],
      "components": [
        {
          "name": "left_foot_frame",
          "mass": 0.018016309759572663,
          "dimensions": [
            0.09,
            0.045,
            0.03825
          ],
          "com": [
            0.004134161361397353,
            1.943645122968221e-20,
            -0.02037258709585519
          ],
          "inertia_tensor": [
            [
              3.5912674486333607e-06,
              -9.047277336272573e-23,
              4.2675158262628113e-07
            ],
            [
              -9.047277336272573e-23,
              1.1641060651440434e-05,
              1.4825539214630055e-22
            ],
            [
              4.2675158262628113e-07,
              1.4825539214630055e-22,
              1.356399711276919e-05
            ]
          ],
          "material": "solid PETG estimate, 1270 kg/m\u00b3",
          "evidence": "generated CAD; actual infill/printed density must be weighed"
        },
        {
          "name": "left_sole",
          "mass": 0.00486,
          "dimensions": [
            0.09,
            0.045,
            0.001
          ],
          "com": [
            0.006,
            0,
            -0.0245
          ],
          "material": "solid TPU 95A, density estimate 1200 kg/m\u00b3",
          "evidence": "estimate; includes adhesive uncertainty, weigh actual sole"
        },
        {
          "name": "left_ankle_servo",
          "mass": 0.0122,
          "dimensions": [
            0.0285,
            0.0122,
            0.0228
          ],
          "com": [
            -0.01425,
            0,
            -0.00475
          ],
          "material": "servo composite",
          "evidence": "seller mass, estimated inertia"
        },
        {
          "name": "left_foot_joint_fasteners",
          "mass": 0.0015,
          "dimensions": [
            0.02,
            0.012,
            0.012
          ],
          "com": [
            0,
            0,
            -0.012
          ],
          "material": "steel and plastic horns",
          "evidence": "estimate; weigh installed fasteners/horn"
        }
      ]
    },
    {
      "name": "right_thigh",
      "mirror_of": "left_thigh",
      "parent": "torso",
      "position": [
        0,
        -0.034,
        -0.03
      ],
      "joint": "right_hip",
      "axis": [
        0,
        1,
        0
      ],
      "limits_deg": [
        -35,
        35
      ]
    },
    {
      "name": "right_shin",
      "mirror_of": "left_shin",
      "parent": "right_thigh",
      "position": [
        0,
        0,
        -0.05
      ],
      "joint": "right_knee",
      "axis": [
        0,
        1,
        0
      ],
      "limits_deg": [
        -10,
        60
      ]
    },
    {
      "name": "right_foot",
      "mirror_of": "left_foot",
      "parent": "right_shin",
      "position": [
        0,
        0,
        -0.05
      ],
      "joint": "right_ankle",
      "axis": [
        1,
        0,
        0
      ],
      "limits_deg": [
        -20,
        20
      ]
    }
  ]
}
```

## 8. Wiring, power and hardware interface

### Hardware interface and power — provisional, no tested firmware

The baseline is six Waveshare 15024 MG90S servos, Pico H, BerryBase 157066 PCA9685, Funduino MPU6050 module, and Mean Well GST40A05-P1J. Do not energize a complete robot until the connector, harness, servo current and fit gates in `procurement.json` pass. No purchases or hardware tests were performed.

#### Power circuit

```mermaid
flowchart TD
  AC[Wall socket] --> Lead[Schuko–C13 lead]
  Lead --> PSU[Enclosed Mean Well 5 V / 5 A PSU]
  PSU --> Cut[Accessible 5 A rated DC disconnect — selection pending]
  Cut --> Bus[Short heavy copper positive and ground buses]
  Bus --> S[Six servo branches; bulk capacitor across bus]
  PC[Laptop USB-A] --> Pico[Pico H USB, logic only]
  Pico --> Logic[3.3 V PCA9685 logic and MPU6050]
  Pico --> PWM[PCA9685 six PWM signal outputs]
  PWM --> S
  Bus --> Ground[Single common ground connection to logic]
  Ground --> Pico
```

**Servo supply current bypasses the Pico, Dupont jumpers, breadboards, and the unverified PCA9685 power traces.** The selected PCA board generates pulses; it does not drive the motors electrically. Its chip's output-current specification concerns signals, not the servo V+ rail. [NXP datasheet](https://www.nxp.com/docs/en/data-sheet/PCA9685.pdf)

A helper prepares six 10 cm JR extensions as a power-injection harness. Keep the signal conductor connected between the male PCA-end connector and the female servo connector. Disconnect the power and return conductors from the PCA-end connector and join their **servo-side** ends to the positive and negative buses. Insulate all cut stubs and joints. Each servo still plugs into a replaceable extension. Add a short logic ground connection at the bus entry. Leave PCA V+ and its motor-power terminal unused. Verify continuity and connector polarity before any servo is attached. This wire preparation is part of the accepted helper job; the student assembles finished parts. The extensions' wire gauge and branch current rating remain unverified.

Use 0.75 mm² copper for buses no longer than 0.10 m each way. Resistance estimate at room temperature is `0.0175 × 0.20 / 0.75 = 0.0047 Ω`; 4.8 A would drop about 0.022 V there, **excluding PSU lead, connectors and individual servo leads**. A 2 m one-way tether of the same wire would drop about 0.45 V at 4.8 A and is unsuitable for a nominal 5 V rail. For the first 0.3 m trials use the PSU's existing lead, place the PSU near the floor test area, and route a slack loop with strain relief close to the torso COM. Several metres require a separately sourced thicker low-resistance cable and longer USB lead; these are not included in the certified-price subtotal.

Current assumptions, **not MG90S measurements**:

| State | Per servo hypothesis | Six-servo total |
|---|---:|---:|
| Loaded standing / slow movement average | 0.10–0.25 A | 0.6–1.5 A |
| Brief acceleration / near stall | 0.8 A | 4.8 A |

Pico, IMU and PWM logic draw from laptop USB, provisionally below 0.15 A combined. A 5 A PSU has only 0.2 A margin against the assumed six-servo peak. The selected servo has **no reliable product-specific current specification**: if measured transients exceed capacity, voltage drops below 4.8 V, or a connector becomes warm, stop and revise the budget/power design. A capacitor does not fix an undersized PSU. At 4.8 A, 1000 µF sustains only roughly 0.04 ms for a 0.2 V drop. It helps short transients, not sustained stalls.

Check loaded voltage at the farthest servo, including the factory PSU lead. The acceptable measured operating range is 4.8–6.0 V; do not assume a nominal 5 V label guarantees 4.8 V at every motor. Keep mains wiring entirely inside commercial leads and the enclosed PSU. [Selected PSU](https://www.berrybase.de/meanwell-schaltnetzteil-5v-dc-5-0a-mit-hohlstecker-5-5x2-1mm)

The required physical cutoff is an accessible **DC unplug connection rated for the full expected current**, near the operator. Its sourcing is still open. Disconnect it to remove servo power; the small downstream capacitor discharges briefly. A mains switch is a useful backup but has PSU hold-up delay. Disabling PWM or sending STOP cannot guarantee an analogue servo releases its last position, and is never equivalent to disconnecting power. Disarm before reconnecting servo power. No rail-voltage or per-servo current measurement is built in.

The €0.50 Goobay 76743 screw adaptor is a researched candidate with an **unknown current rating**, not a verified 5 A solution. The €1.80 BerryBase DCKSW cable is unavailable and also lacks a confirmed suitable DC rating. Neither is accepted to close the basket. [Adaptor](https://www.berrybase.de/dc-kupplung-fuer-hohlstecker-5-5x2-1mm-schraubmontage-terminal-block-2-pin), [switch cable](https://www.berrybase.de/dc-kabel-mit-schalter-5-5x2-1mm-stecker-5-5x2-1mm-buchse-35cm)

#### Logic wiring

| Pico signal / physical pin | Connection |
|---|---|
| 3V3 OUT / 36 | PCA VCC and IMU VCC, both 3.3 V logic |
| GND / 38 | PCA GND, IMU GND and short connection to servo return bus |
| GP4 / 6 | I2C0 SDA, both boards |
| GP5 / 7 | I2C0 SCL, both boards |
| GP6 / 9 | PCA OE, 10 kΩ pull-up to 3.3 V |
| USB Micro B | USB data and Pico power |

The Pico never connects servo 5 V to VBUS, VSYS or 3V3. Use one short I2C bus at 400 kHz, PCA default address 0x40, IMU address 0x68 with AD0 grounded; scan first. Verify both modules' pull-ups go to **3.3 V**, not servo 5 V. Set MPU6050 ±16 g, ±2000°/s, approximately 44 Hz digital filtering and 200 Hz sample rate. Rotate the measured sensor axes into torso x-forward/y-left/z-up coordinates before passing samples to the shared estimator. [Pico pinout](https://datasheets.raspberrypi.com/pico/Pico-R3-A4-Pinout.pdf), [MPU6050 registers](https://invensense.tdk.com/wp-content/uploads/2015/02/MPU-6000-Register-Map1.pdf)

PCA channels 0–5: left hip, left knee, left ankle, right hip, right knee, right ankle. Set actual PWM frame frequency to 50 Hz and calibrate its oscillator; nominal PWM resolution is about 4.88 µs per tick. Configure OE-high outputs LOW. The board may have an onboard OE pull-down: remove/change it if necessary so the external pull-up actually disables outputs during Pico reset. Verify the power-up waveform before attaching horns. The selected servo's 3.3 V signal threshold is unknown and must pass a one-servo bench test. Do not assume every MG90S-labelled servo has identical electronics.

Helper soldering: any loose IMU/PCA headers, six signal output pins if not fitted, OE pull-up, capacitor and power-injection harness. A temperature-controlled iron, flux-core solder, cutters/stripper, heat-shrink and multimeter suffice. Borrow the school's equipment if possible; tools are excluded from the component budget. Solder/heat preparation happens away from attached servos and USB. No frame drilling, sawing, tapping or heat-set inserts are planned.

#### Version 1 serial protocol

USB CDC, nominal serial baud 460800, ASCII newline packets, at most **192 bytes including newline**. No dynamically growing input buffer. Payload ends in `*HHHH\n`, CRC-16/CCITT with initial 0xFFFF (Python `binascii.crc_hqx`). SI units in Python; integer milliradians, millimetres/s² and milliradians/s on the wire. Use monotonic local timestamps modulo 2³² ms. USB baud is a descriptor setting, not the native CDC throughput limit.

| Payload before checksum | Purpose |
|---|---|
| `H,1,seq,pc_ms` | Hello/configuration query |
| `I,1,seq,mcu_ms,digest,cal_valid` | Hello response: lowercase 64-character SHA-256 digest and calibration validity 0/1 |
| `A,1,seq,pc_ms,1` | Explicit arm request |
| `A,1,seq,pc_ms,0` | Disarm request, always permitted |
| `C,1,seq,pc_ms,q0,q1,q2,q3,q4,q5` | Six validated target angles |
| `S,1,seq,pc_ms` | Stop: disable PWM and latch stop fault |
| `R,1,seq,pc_ms` | Clear faults only while disarmed and after their causes have been corrected; does not arm |
| `T,1,ack_seq,mcu_ms,status,q0,...,q5,ax,ay,az,gx,gy,gz` | Applied-target acknowledgement plus raw IMU sample, 200 Hz |

Status bit mask: 1 armed; 2 watchdog fault; 4 invalid command; 8 sensor/configuration fault; 16 stopped. Any fault is latched and disarms; rearming requires explicit fault clear after cause correction and a new handshake. Header sequence is uint16, time uint32; reject duplicates, stale packets and backward sequences with modulo comparison (`0 < delta < 32768`). More than 100 ms since a **valid fresh C command** disables PWM. Hello and telemetry do not refresh the command watchdog. PC monitors missing telemetry with its own 100 ms deadline. Neither clock is presumed synchronized. Use relative deltas and record receive times; handshake measures offset/round-trip latency.

Use one increasing PC sequence counter for all control packets. Only perform a new H handshake while disarmed. At H receipt, MCU records `pc_to_mcu_offset = mcu_receive_ms - pc_ms` modulo 2³². Convert later C timestamps with that offset, using signed wrap-safe differences; reject commands with inferred age above 80 ms or more than 20 ms in the future. PC checks handshake round-trip time is below 20 ms before requesting ARM. These provisional timing tolerances require bench measurement. A packet with a new sequence but old timestamp must not refresh the watchdog. Telemetry repeats the latest **applied C sequence**, so the PC permits repeated acknowledgements while independently requiring advancing MCU sample timestamps and rejecting duplicate/backward IMU samples.

`hardware_interface.py` implements bounded command encoding, CRC validation, telemetry parsing and per-servo calibrated pulse mapping. Command endpoints round inward to avoid quantized unsafe angles. `H/I/A/S/R` are protocol specifications, not implemented MCU handlers in this delivery. Digest is SHA-256 of the exact shared calibration/configuration file bytes agreed by PC and MCU; this file must include joint order, signs, angle limits, zero pulses, pulse gains, slew limit and IMU rotation/bias. Do not use the simulation-only XML hash as the hardware configuration digest. A receiver must validate exact packet kind, field count, integer range, CRC and version before any state change. Flush overlong input until newline, latch error, and keep outputs disabled. Never accept Python pickles, executable text, or unbounded JSON.

Applied targets describe the **post-validation, post-delay, post-rate-limiter commands** written to PWM. They are not measured shaft angles. Telemetry repeats the latest applied targets between 50 Hz updates. Do not label acknowledged angles “joint feedback.” Calibrate each channel's centre pulse, sign, µs/radian gain and safe pulse endpoints; there is no universal safe 500–2500 µs mapping.

#### MCU and PC pseudocode

```text
BOOT:
  OE = HIGH; PWM outputs LOW; state = DISARMED
  load measured calibration; refuse ARM if absent or corrupt
  configure I2C, PCA 50 Hz, IMU 200 Hz; verify communication
  set applied targets to HOME but do not enable PWM

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

PC (initially hardware disconnected; no automatic ARM):
  load policy and matching physical/control/calibration configuration
  handshake, check version/order/calibration, initialize filter from rest IMU
  at each timestamped IMU sample:
      GravityEstimator.update(gyro, accel, measured_dt)
      check gyro/accel saturation, faults and freshness
  every 20 ms:
      frame = gravity(3), gyro/10(3), latest applied targets normalized(6),
              previous requested policy action(6)
      append to the same five-frame ObservationHistory
      policy predicts action; use action_to_target; send C frame
      remember requested action
  operator explicitly arms for a limited supervised trial
  fault, tilt >60 degrees, missing telemetry or Ctrl-C => send STOP;
      operator disconnects DC power and manually resets the robot
```

Initialize history with five copies of the measured resting frame, as in simulation. The simulator's initial 0.2 s settling interval does not replace a real startup check. Nominal command delay is a **provisional total PC-command to acknowledged-PWM delay** of 20 ms; at 50 Hz the random 20–40 ms delay often rounds to the next 40 ms tick. Do not add another guessed delay to the MCU until timings are measured. Servo shaft lag is represented separately by finite position-control dynamics. Timestamp comparisons need wrap handling and missed-tick rejection. This pseudocode requires implementation and electrical testing before hardware deployment.

Protect the USB lead and heavy power lead with a slack loop. Keep connector mass supported externally where possible. Cable force is not simulated, so record routing and direction in every physical trial. Never reset an RL episode by commanding an uncontrolled fallen robot back to HOME. Cut power, pick it up, inspect gears/brackets, then reinitialize.

The helper needs a temperature-controlled soldering iron, solder, cutters/stripper and borrowed multimeter; these are tools and excluded from part cost. No equipment price was verified because helper use is assumed. The exact tasks are header/terminal assembly where supplied loose, sensor headers, OE pull-up adjustment if needed, and insulated direct power-injection harness joints. The student receives a ready-made harness and performs screw/plug assembly. Never bypass the power-connection rating gate just to avoid a small solder job.

## 9. MuJoCo and control parameter table

| Parameter | Starting value | Provenance / limitation |
|---|---|---|
| Total modeled mass | 0.208431 kg | Design ledger, not weighed hardware |
| Physics / integrator | 0.002 s; implicitfast | Numerical choice, locally compiled |
| Gravity | 0, 0, −9.81 m/s² | Indoor Earth approximation |
| Hip / knee / ankle limits | [−35,35] / [−10,60] / [−20,20]° | Software-safe hypotheses, calibrate actual range |
| Position kp / velocity kv | 0.9 N·m/rad / 0.012 N·m·s/rad | Estimated internal-servo response |
| Peak simulated actuator force | ±0.08 N·m | Estimated intermittent envelope; physical servo cannot enforce this setting |
| Torque-speed envelope | Available drive torque falls linearly toward seller unloaded speed | Simple DC-like estimate; braking torque retained, backdrive not hard speed clipped |
| Unloaded shaft speed reference | 60° / 0.11 s = 545°/s at 4.8 V | Selected seller claim, measure at actual 5 V/load |
| Command slew | 180°/s, at most 3.6° per 20 ms update | Target trajectory limit; **not a measured shaft-speed limit** |
| Command delay | 20 ms nominal; 20–40 ms DR | Estimate; delayed commands applied on 50 Hz ticks |
| Target deadband | 0.5° | Command hysteresis surrogate; not true gear backlash |
| Joint damping / friction loss / armature | 0.002 N·m·s/rad / 0.001 N·m / 5e−6 kg·m² | Estimated passive gearbox properties |
| Contact friction | 0.8 sliding, 0.005 torsional, 0.0001 rolling | Ground/TPU contact estimates; MuJoCo torsional/rolling coefficients have different units from sliding |
| Foot contact | Flat plate plus 1 mm sole box | Simple primitive, whole-foot clearance used for evaluation |
| Gyro / acceleration noise | 0.006 rad/s / 0.04 m/s² standard deviation | Conservative hypotheses, not measured MPU6050 noise |
| Gravity filter | 0.5 s blending time; 0.8–1.2 g acceptance window | Shared preprocessing choice, sensitive to sustained acceleration |

Position actuators implement bounded `kp(target − angle) − kv velocity`. The environment adds command queue latency, post-delay target slew, hysteresis and a direction-dependent torque-speed envelope. Joint motion remains dynamic. True actuator force limits exist in simulation only; hobby PWM hardware has no current/torque telemetry or programmable torque protection. Software angle/rate limits reduce risk but cannot prevent damage during stalls/falls. Model choice follows the [MuJoCo XML actuator reference](https://mujoco.readthedocs.io/en/latest/XMLreference.html).

Reward each 20 ms step is `dt × [10 clip(vx, −0.05, 0.06) + 0.2 upright − 0.5 abs(vy) − 0.0001 mean(action_rate²)]`, minus 2 on a fall. Capped forward progress discourages explosive speed; upright rewards standing; lateral motion discourages drift; command-rate penalty discourages abrupt actions. This is a **smoothness proxy, not measured electrical energy**. Ground-truth simulation motion is permitted for rewards/metrics, never policy observations. The simple reward admits standing as a local optimum; observed smoke results demonstrate that limitation.

Fall means root height below 60% of home height, tilt beyond 60°, or non-foot floor contact. A fall terminates; 30 s without a fall truncates. Training reset has a 0.2 s settling period excluded from reported episode duration. Physical reset is manual. Evaluation counts a lifted step only after landing, following **at least 40 ms continuous whole-foot clearance ≥3 mm with opposite-foot contact**. Alternating qualifying landings are counted separately. Success requires ≥0.3 m travel, no fall, at least two qualifying steps on each side and three alternations within 30 s. Sliding, toe pivots and hops without opposite-foot support do not meet this metric.

## 10. Full `robot.xml`

Save this as `robot.xml` beside the Python files and supplied `cad/stl/` directory. Meshes are visual only; primitive geometry handles contact. `build_model.py` regenerates XML from the ledger.

```xml
<!-- Generated from physical_spec.json; provisional hardware model. -->
<mujoco model="SchoolBipedS6_provisional">
  <compiler angle="radian" autolimits="true" inertiafromgeom="false" />
  <option timestep="0.002" gravity="0 0 -9.81" integrator="implicitfast" iterations="60" />
  <visual>
    <global offwidth="960" offheight="720" />
    <map znear="0.002" />
  </visual>
  <default>
    <joint limited="true" damping="0.002" armature="0.000005" frictionloss="0.001" />
    <geom condim="3" friction="0.8 0.005 0.0001" solref="0.008 1" solimp="0.9 0.95 0.001" />
    <position kp="0.9" kv="0.012" forcelimited="true" forcerange="-0.08 0.08" ctrllimited="true" />
  </default>
  <asset>
    <mesh name="torso_mesh" file="cad/stl/torso.stl" scale="0.001 0.001 0.001" />
    <mesh name="left_thigh_mesh" file="cad/stl/left_thigh.stl" scale="0.001 0.001 0.001" />
    <mesh name="left_shin_mesh" file="cad/stl/left_shin.stl" scale="0.001 0.001 0.001" />
    <mesh name="left_foot_mesh" file="cad/stl/left_foot.stl" scale="0.001 0.001 0.001" />
    <mesh name="right_thigh_mesh" file="cad/stl/right_thigh.stl" scale="0.001 0.001 0.001" />
    <mesh name="right_shin_mesh" file="cad/stl/right_shin.stl" scale="0.001 0.001 0.001" />
    <mesh name="right_foot_mesh" file="cad/stl/right_foot.stl" scale="0.001 0.001 0.001" />
  </asset>
  <worldbody>
    <light pos="0 -1 2" dir="0 0 -1" diffuse="0.8 0.8 0.8" />
    <geom name="floor" type="plane" size="3 3 0.05" rgba="0.87 0.88 0.90 1" />
    <body name="torso" pos="0 0 0.154240388">
      <geom name="torso_visual" type="mesh" mesh="torso_mesh" contype="0" conaffinity="0" group="2" rgba="0.12 0.55 0.83 1" />
      <inertial mass="0.08188624774" pos="-0.007350467977 0 -0.008997271212" fullinertia="8.105527885e-05 5.228548807e-05 4.64646527e-05 2.541098842e-21 8.152129337e-06 0" />
      <freejoint name="root" />
      <geom name="torso_collision" type="box" pos="0 0 0.01" size="0.02 0.041 0.025" rgba="0.10 0.45 0.8 0.8" />
      <site name="imu_site" pos="-0.0255 0 0.018" size="0.003" rgba="1 0.7 0 1" />
      <camera name="overview" pos="0.42 -0.5 0.24" xyaxes="0.766 0.643 0 -0.26 0.31 0.916" />
      <geom name="left_hip_servo_case" type="box" pos="0 0.01975 -0.03475" size="0.0061 0.01425 0.0114" rgba="0.15 0.15 0.17 1" />
      <geom name="right_hip_servo_case" type="box" pos="0 -0.01975 -0.03475" size="0.0061 0.01425 0.0114" rgba="0.15 0.15 0.17 1" />
      <body name="left_thigh" pos="0 0.034 -0.03">
        <geom name="left_thigh_visual" type="mesh" mesh="left_thigh_mesh" contype="0" conaffinity="0" group="2" rgba="0.12 0.55 0.83 1" />
        <inertial mass="0.01897302956" pos="7.38254531e-20 -0.009433651865 -0.04297017599" fullinertia="1.075607705e-05 9.509006643e-06 2.306096954e-06 -1.321364545e-23 9.846621791e-24 -2.552040829e-06" />
        <joint name="left_hip" type="hinge" axis="0 1 0" range="-0.6108652382 0.6108652382" />
        <geom name="left_thigh_link" type="capsule" fromto="0 0 -0.006 0 0 -0.044" size="0.006" rgba="0.12 0.55 0.83 1" />
        <geom name="left_knee_servo_case" type="box" pos="0 -0.01425 -0.05475" size="0.0061 0.01425 0.0114" rgba="0.15 0.15 0.17 1" />
        <body name="left_shin" pos="0 0 -0.05">
          <geom name="left_shin_visual" type="mesh" mesh="left_shin_mesh" contype="0" conaffinity="0" group="2" rgba="0.12 0.55 0.83 1" />
          <inertial mass="0.007723103503" pos="0.001431986556 0.001714317795 -0.0226881703" fullinertia="3.771568488e-06 3.870592897e-06 4.366762365e-07 1.069363096e-08 2.608766246e-07 -1.717283681e-07" />
          <joint name="left_knee" type="hinge" axis="0 1 0" range="-0.1745329252 1.047197551" />
          <geom name="left_shin_link" type="capsule" fromto="0 0 -0.006 0 0 -0.044" size="0.006" rgba="0.12 0.55 0.83 1" />
          <body name="left_foot" pos="0 0 -0.05">
            <geom name="left_foot_visual" type="mesh" mesh="left_foot_mesh" contype="0" conaffinity="0" group="2" rgba="0.12 0.55 0.83 1" />
            <inertial mass="0.03657630976" pos="-0.001919484737 9.573768603e-21 -0.0153667454" fullinertia="7.376615256e-06 2.141873222e-05 2.153521221e-05 -9.259259754e-23 2.911645236e-06 1.500083034e-22" />
            <joint name="left_ankle" type="hinge" axis="1 0 0" range="-0.3490658504 0.3490658504" />
            <geom name="left_foot_plate" type="box" pos="0.006 0 -0.0225" size="0.045 0.0225 0.0015" rgba="0.08 0.36 0.65 1" />
            <geom name="left_foot_sole" type="box" pos="0.006 0 -0.0245" size="0.045 0.0225 0.0005" rgba="0.15 0.15 0.15 1" />
            <site name="left_foot_sole_center" pos="0.006 0 -0.025" size="0.001" />
            <geom name="left_ankle_servo_case" type="box" pos="-0.01425 0 -0.00475" size="0.01425 0.0061 0.0114" rgba="0.15 0.15 0.17 1" />
          </body>
        </body>
      </body>
      <body name="right_thigh" pos="0 -0.034 -0.03">
        <geom name="right_thigh_visual" type="mesh" mesh="right_thigh_mesh" contype="0" conaffinity="0" group="2" rgba="0.12 0.55 0.83 1" />
        <inertial mass="0.01897302956" pos="7.38254531e-20 0.009433651865 -0.04297017599" fullinertia="1.075607705e-05 9.509006643e-06 2.306096954e-06 1.321364545e-23 9.846621791e-24 2.552040829e-06" />
        <joint name="right_hip" type="hinge" axis="0 1 0" range="-0.6108652382 0.6108652382" />
        <geom name="right_thigh_link" type="capsule" fromto="0 0 -0.006 0 0 -0.044" size="0.006" rgba="0.12 0.55 0.83 1" />
        <geom name="right_knee_servo_case" type="box" pos="0 0.01425 -0.05475" size="0.0061 0.01425 0.0114" rgba="0.15 0.15 0.17 1" />
        <body name="right_shin" pos="0 0 -0.05">
          <geom name="right_shin_visual" type="mesh" mesh="right_shin_mesh" contype="0" conaffinity="0" group="2" rgba="0.12 0.55 0.83 1" />
          <inertial mass="0.007723103503" pos="0.001431986556 -0.001714317795 -0.0226881703" fullinertia="3.771568488e-06 3.870592897e-06 4.366762365e-07 -1.069363096e-08 2.608766246e-07 1.717283681e-07" />
          <joint name="right_knee" type="hinge" axis="0 1 0" range="-0.1745329252 1.047197551" />
          <geom name="right_shin_link" type="capsule" fromto="0 0 -0.006 0 0 -0.044" size="0.006" rgba="0.12 0.55 0.83 1" />
          <body name="right_foot" pos="0 0 -0.05">
            <geom name="right_foot_visual" type="mesh" mesh="right_foot_mesh" contype="0" conaffinity="0" group="2" rgba="0.12 0.55 0.83 1" />
            <inertial mass="0.03657630976" pos="-0.001919484737 -9.573768603e-21 -0.0153667454" fullinertia="7.376615256e-06 2.141873222e-05 2.153521221e-05 9.259259754e-23 2.911645236e-06 -1.500083034e-22" />
            <joint name="right_ankle" type="hinge" axis="1 0 0" range="-0.3490658504 0.3490658504" />
            <geom name="right_foot_plate" type="box" pos="0.006 0 -0.0225" size="0.045 0.0225 0.0015" rgba="0.08 0.36 0.65 1" />
            <geom name="right_foot_sole" type="box" pos="0.006 0 -0.0245" size="0.045 0.0225 0.0005" rgba="0.15 0.15 0.15 1" />
            <site name="right_foot_sole_center" pos="0.006 0 -0.025" size="0.001" />
            <geom name="right_ankle_servo_case" type="box" pos="-0.01425 0 -0.00475" size="0.01425 0.0061 0.0114" rgba="0.15 0.15 0.17 1" />
          </body>
        </body>
      </body>
    </body>
  </worldbody>
  <actuator>
    <position name="left_hip_servo" joint="left_hip" ctrlrange="-0.6108652382 0.6108652382" />
    <position name="left_knee_servo" joint="left_knee" ctrlrange="-0.1745329252 1.047197551" />
    <position name="left_ankle_servo" joint="left_ankle" ctrlrange="-0.3490658504 0.3490658504" />
    <position name="right_hip_servo" joint="right_hip" ctrlrange="-0.6108652382 0.6108652382" />
    <position name="right_knee_servo" joint="right_knee" ctrlrange="-0.1745329252 1.047197551" />
    <position name="right_ankle_servo" joint="right_ankle" ctrlrange="-0.3490658504 0.3490658504" />
  </actuator>
  <sensor>
    <gyro name="imu_gyro" site="imu_site" />
    <accelerometer name="imu_accel" site="imu_site" />
  </sensor>
  <keyframe>
    <key name="home" qpos="0 0 0.154240388 1 0 0 0 -0.1745329252 0.1745329252 0 -0.1745329252 0.1745329252 0" ctrl="-0.1745329252 0.1745329252 0 -0.1745329252 0.1745329252 0" />
  </keyframe>
</mujoco>
```
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

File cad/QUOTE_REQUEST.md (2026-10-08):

# Quotation brief — not submitted and not an actual quotation

Please price the supplied **seven named PETG frame STLs once each**, plus **two named TPU sole STLs once each**. Ignore `quotation_plate.stl` for quantities: it duplicates the seven frames and is only a geometric grouping.

PETG: 0.2 mm layers, 3 perimeters, nominal 25% infill, stiff joint walls. TPU 95A: 90×45×1 mm soles, bonded to their feet with adhesive included. Supply parts cleaned, supports removed, holes clear for assembly with screws; the student has no drill/printer/taps. Please include German VAT, shipment, all finishing and a matched fastener kit. See `ASSEMBLY.md` for provisional fastener quantities. Please confirm layer orientation, dimensional tolerance and the mounting interfaces against a sample of the selected Waveshare 15024 MG90S and its actual supplied horns before manufacture.

The CAD is currently a **quotation/fit prototype**, not a manufacturing release. Servo shaft/ear/horn measurements must be supplied before final printing. Cost changes after those fit changes require a revised quote. No purchase authorization is implied by requesting a price.

Automatic service candidates researched: [Meltlab](https://meltlab.de/preise) and [Printfaktur](https://printfaktur.de/). No automatic upload/browser was available in this session, so no price was obtained. The remaining budget is only **€9.68 for printing, all unresolved fasteners/horns, and the current-rated power connection together**, using the current sourced basket. This number is a budget constraint, never a printing quotation. School lab/donated manufacturing could change cost, but is not assumed.

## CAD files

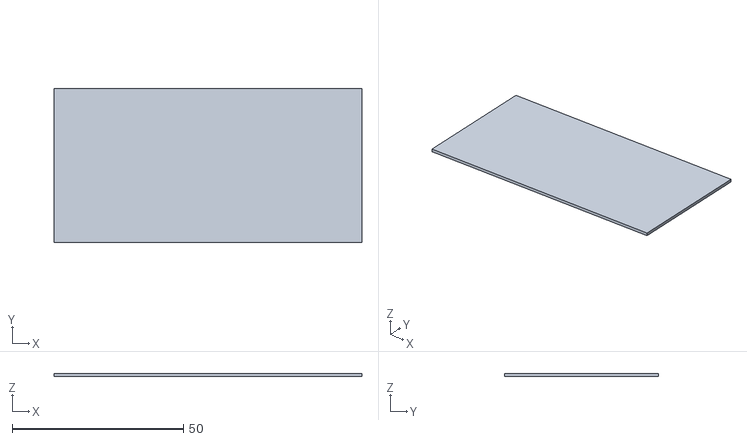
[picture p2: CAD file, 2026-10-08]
cad/stl/left_sole.stl
90.0 x 45.0 x 1.00

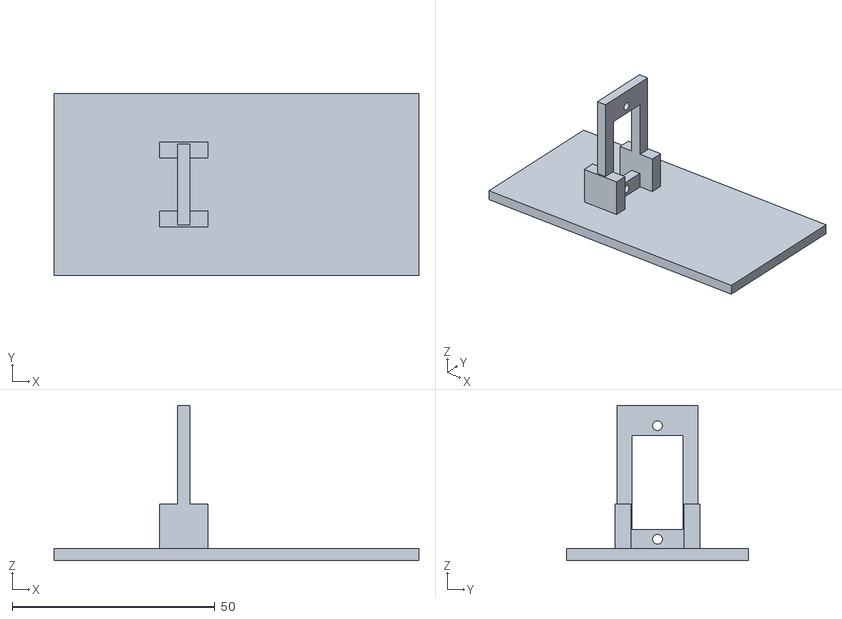
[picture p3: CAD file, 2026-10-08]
cad/stl/right_foot.stl
90.0 x 45.0 x 38.2

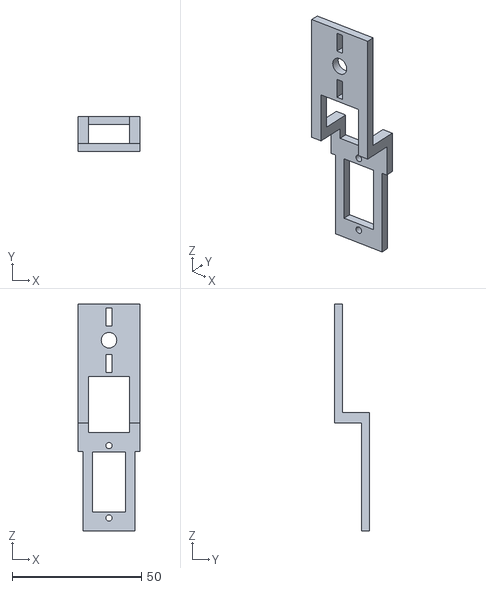
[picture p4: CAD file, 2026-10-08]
cad/stl/right_thigh.stl
24.0 x 13.5 x 87.8

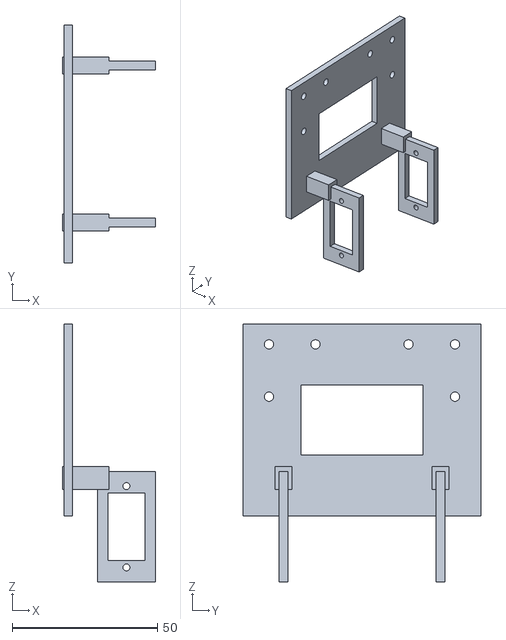
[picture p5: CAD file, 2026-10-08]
cad/stl/torso.stl
32.0 x 82.0 x 88.8

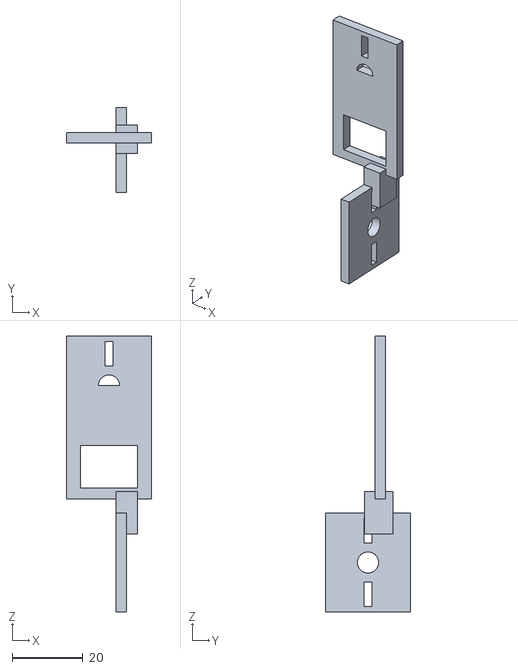
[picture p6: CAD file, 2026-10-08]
cad/stl/left_shin.stl
24.0 x 24.0 x 78.0

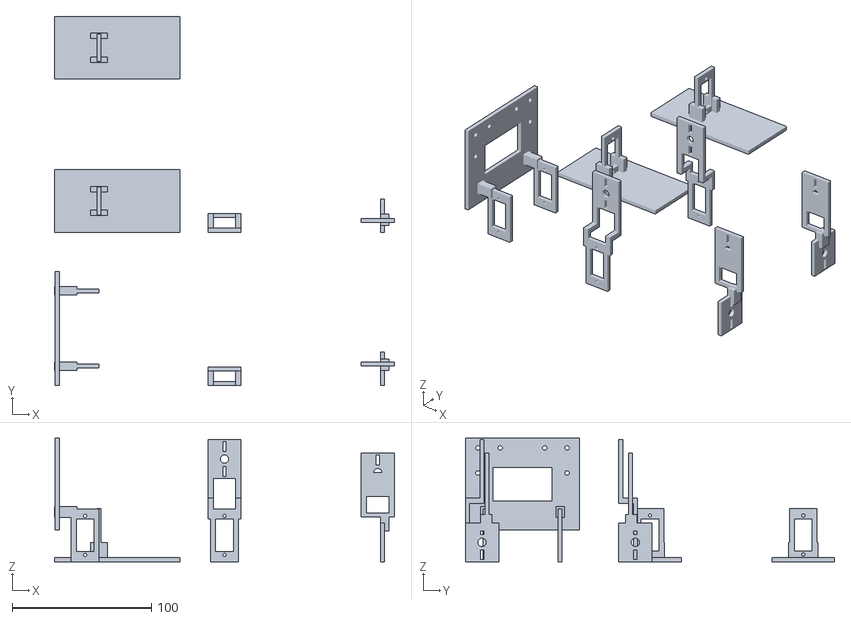
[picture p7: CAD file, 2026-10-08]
cad/stl/quotation_plate.stl
244.0 x 265.0 x 88.8

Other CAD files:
cad/stl/left_thigh.stl
cad/stl/right_shin.stl
cad/stl/left_foot.stl

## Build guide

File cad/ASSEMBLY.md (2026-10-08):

# S6 assembly prototype — fit gate remains open

Editable CAD is `build_frame.py`; dimensions in millimetres are derived from `../physical_spec.json`. `stl/` contains seven PETG frame components and two separate TPU soles. `quotation_plate.stl` is a cost-estimation grouping, not a recommended print-bed arrangement. Individual parts fit within approximately 90 mm; a service chooses orientation/supports. `exploded.png` shows body/part names and axes.

**Do not order these as manufacturing-ready parts.** CAD passes a finite intersection audit, but the selected servo's ear, shaft, spline, horn pattern and screws are unmeasured. The intended finished kit requires clear through-holes, removed supports and bonded soles; no drilling, cutting, tapping or heat-set inserts by the assembler. The supplier must provide any necessary finishing and matching fasteners within the delivered quote.

Materials: PETG frames, 0.2 mm layers, 3 perimeters, nominal 25% infill; TPU 95A soles 90×45×1 mm bonded to feet. The mass specification uses solid PETG at 1270 kg/m³ as a conservative estimate; actual infill/adhesive mass must be weighed. Layers should be oriented to resist ear loads rather than split across narrow bridges. Ask for stiff local joint mounting walls, smooth holes and no support debris near rotating horns. Service capability and cost for TPU/bonding are not verified.

## Fastener schedule — provisional, quote as a complete kit

| Purpose | Quantity | Proposed type / unresolved fit |
|---|---:|---|
| Servo housing mounting ears | 12 | M2×8 through screws + 12 M2 nuts + 24 washers; verify real ear holes and combined thickness |
| Horn shaft retention | 6 | Servo-specific factory screws; thread and supplied inclusion unknown |
| Horn to moving frame | 12 | Two per horn, matched small screws/washers; factory horn pilot holes and screw lengths unknown |
| Pico/PCA/IMU mounting | 8 ties | Through prepared frame holes; immobilize IMU and keep board faces clear of plastic/metal |
| Main cable strain relief | 4 ties | At torso near COM; externally support connector weight |
| Servo harness restraints | 8 ties | Leave a service loop at every joint; no wires crossing horn sweep |

The CAD horn interface has a 6 mm central access opening and two 2.4 mm-wide radial slots. It is a fit concept, not evidence that the included horns/screws match. If a factory horn cannot fasten without modifying it, **revise/quote the interface before printing**, or have the supplier deliver matched adapters; include their price/mass. Do not press in an incompatible spline or use glue as a structural joint.

## Assembly sequence after the budget/fit gate passes

1. Identify L/R frame parts and six individually calibrated servos. Servo housing and lead-out dimensions must match the kit. Inspect prints and holes; return poor prints for finishing rather than drilling them.
2. Test electronics and one servo without a limb attached. Disable outputs and disconnect motor power before installing a horn. Centre the unloaded servo to its calibrated **zero-joint** pulse, then turn power off. Mount horn and retain it with its matching centre screw; do not use the HOME angle as the mechanical zero reference.
3. Mount two hip servo cases to the torso ear cradles, shafts facing outward ±y. Attach each thigh moving plate to that hip's horn with two matched screws. There is no passive hip roll axis.
4. Mount each knee servo case to its thigh's lower cradle. Attach the shin's upper plate to the knee horn. Both simulated pitch axes are +y; the physical right-hand motor sign may be opposite and is corrected in calibration.
5. Mount ankle servo case to its foot's upright cradle with shaft facing +x. Attach the shin's perpendicular lower plate to the ankle horn. Foot and ankle servo case rotate together; the shin carries the horn. The ankle axis is +x, roll only.
6. Bonded TPU soles should already be on the feet. Install boards at the coordinates in the specification using prepared holes/ties; do not put a tie over connector pins or strain the board. IMU must be rigidly immobilized and its measured axis rotation recorded.
7. Route servo leads and prepared extension harness; verify polarity/continuity with motor supply disconnected. Leave a slack service loop and inspect every safe angle manually without forcing the gearbox. Add USB/power strain relief.
8. Assemble and weigh one leg, then the entire robot. Confirm pitch/roll signs with very small unloaded motions. Test physical cutoff, watchdog and reboot-disarmed state before supported HOME `(-10°, +10°, 0°)` per leg.
9. On a low clear floor area with thin protection, test stationary poses and increase test length gradually. For a fall, disconnect power, inspect gears/ears, manually pick up and reset. Optional safety thread stays slack and is not required to hold the robot upright.

The finite CAD report does not certify horn fasteners, servo-ear insertion, electronics mounting or every continuous-motion clearance. Simulation contact primitives approximate the structure and do not test printed layer strength. The complete robot has not been assembled.

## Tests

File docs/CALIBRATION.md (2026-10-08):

# Parameters to measure on the real robot

All numbers currently in `physical_spec.json` and `robot_config.py` are estimates except the explicitly labelled seller claims. A school kitchen scale, ruler, protractor, phone camera, known weights and a borrowed multimeter are enough to replace many estimates. No prolonged stall tests.

| Parameter | Inexpensive procedure | Where it goes |
|---|---|---|
| Housing/ears/shaft/horns | Photograph one servo against a ruler, measure ear hole pitch/diameter, shaft centre relative to the body, axial shaft height, horn screw thread, horn holes, supplied screws and lead exit. Have a sample printed interface checked before all prints. | `physical_spec.json` servo dimensions; `cad/build_frame.py` cradle/horn geometry |
| Angle range, offsets, sign | With one unloaded unmounted horn, start near a measured centre pulse. Increase in small increments; stop before buzzing or mechanical stops. Use a protractor/video. Repeat from both directions. Fit angle versus pulse, record sign and repeatability for all six servos. Shrink safe angles 5–10° from measured ends. | Physical joint limits/HOME in JSON; MCU calibration arrays; action map reads JSON |
| Backlash/deadband | Power off and gently reverse a tiny known load; film horn position. Compare pulse-angle curves approaching the same angle from both directions. Distinguish gear play from commanded deadband and structural flex. | `SERVO_DEADBAND`; potentially a shaft-play model; measured offset/noise ranges |
| Unloaded and loaded speed | Film a 10–20° step at 120/240 fps alongside timestamped command/ack LEDs or screen. Repeat with a safe small load in both directions, at measured servo voltage. | No-load speed envelope, target slew limit, kp/kv fitted jointly |
| Command and shaft latency | Log PC send, MCU receive, PWM apply and ack timestamps. Film the first shaft movement. Measure distribution over at least 100 commands. Synchronize clocks via handshake; do not call round-trip time one-way latency. | `BASE_DELAY`, DR delay interval, controller scheduling; position-actuator response parameters |
| Approximate usable torque | Clamp a single test servo in a finished holder, attach a known short lever and known mass. Torque = mass × 9.81 × perpendicular lever length. Increase briefly until tracking deteriorates, then back off substantially. E.g. 100 g at 20 mm gives 0.0196 N·m. Test repeated gentle holds/moves with temperature and current checks. Stop on buzzing, hot case or rapid voltage sag. | Intermittent `SERVO_TORQUE` and strength uncertainty; this is not an industrial continuous rating |
| Current and voltage | Measure single-servo rest/movement/brief loaded current, then total on a conservative pose. Use correct meter range/fused current jack; measure current in series and voltage in parallel. Phone video captures intermittent readings, but a basic meter may miss peaks. Check voltage at the farthest servo and connector temperature. | PSU/harness feasibility and current assumptions; optional measured supply-droop model |
| Total and body masses | Weigh servo with lead, frame, horn/fasteners, PCB/headers, sole and attached wire separately. Then weigh each assembled rigid body and the complete robot. Assign every item once, including lead sections on the body that carries them. Support the tether externally. | JSON component masses; rerun `build_model.py`; aim <250 g |
| COM/inertia | Balance each unpowered assembled rigid body on two perpendicular edges or suspend it from two points; intersect plumb lines for COM. Use measured dimensions and mass distribution for box/parallel-axis inertia. More accurate inertia requires a pendulum experiment, not necessary initially. | JSON component COM and optional inertia tensor; all inertia entries kg·m² |
| Foot friction | Finished sole on intended flat material: slowly incline a board and note sliding angle θ. Start coefficient estimate μ ≈ tan(θ); repeat at different loads and orientations. This approximates static friction; dynamic friction may differ. | Floor/sole sliding friction; DR ±15% only if measurements support it |
| Joint friction/damping | Compare slow forward/reverse sweeps under known small loads, and commanded step settling videos. Powered-off servos resist motion through gears; do not force them. Fit passive friction/damping together with active gains, not from one video. | MJCF joint damping/frictionloss; recalibrate after wear |
| IMU biases and alignment | Record 30–60 s at rest in several known orientations, use +/− axis gravity poses. Subtract stationary gyro bias; fit accelerometer offset/scale and sensor-to-torso rotation. Keep the MCU outputs in the torso convention used by MuJoCo. | MCU bias/axis transform, estimator calibration, measured DR biases/noise |
| IMU noise | Record stationary 200 Hz samples and report per-axis standard deviation, bias drift, clipping and timestamps. Fit randomization from actual distributions. Repeat with servos powered. | GYRO_NOISE, ACCEL_NOISE, DR sensor scale/bias |
| Tether disturbance | Repeat identical standing trials with cable slack in different directions. Weigh unsupported cable section and video its pull. | Experimental confound; later conservative external-force randomization if needed |

Fit servo response from several amplitudes/loads, not one fast motion. The XML position actuator, torque-speed envelope and target deadband are approximations: gain tuning cannot recover missing feedback or a gearbox failure. Keep calibration records per physical servo so replacement parts can be remeasured.

After mechanical edits: regenerate CAD, review clearances, update **measured** body masses/COM/inertia in JSON, then generate MJCF. `tools/sync_frame_mass.py` overwrites frame mass with a solid CAD estimate: **do not run it over measured masses**. Use it only while designing the prototype. Update model and controller safe limits together; old policies are invalid when geometry, joint order, angle mapping or observation preprocessing change. Keep a versioned measured specification beside every training result.

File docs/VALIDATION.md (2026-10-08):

# Executed verification — 8 October 2026

These are **local software results**. No hardware was purchased, assembled, weighed or tested. No printing quotation was obtained. The complete delivered BOM is still incomplete; `tools/budget_gate.py` exits 2 and prohibits procurement clearance.

Linux/Python 3.12 was used in `.venv`. The pinned runtime dependency set installed successfully; `uv pip check` reported all 47 installed packages compatible. `pytest` passed all **12 tests**, including MuJoCo compilation, mass accounting, positive joint directions, home contacts, 30 s neutral standing, finite bounded-random/limit command runs, action mapping, shaft lag, delayed/slew-limited commands, observation construction, exact seeded resets, randomization restoration, CRC/bounds, torque-independent pulse calibration and foot-step classification. The environment also passed SB3 `check_env`.

## Reproducible commands

```bash
MPLCONFIGDIR=/tmp/robot-mpl XDG_CACHE_HOME=/tmp/robot-cache .venv/bin/python -m pytest -q
.venv/bin/python tools/check_clearance.py
.venv/bin/python tools/torque_estimates.py
.venv/bin/python tools/budget_gate.py
MPLCONFIGDIR=/tmp/robot-mpl XDG_CACHE_HOME=/tmp/robot-cache .venv/bin/python train.py --steps 10240 --seed 0 --output runs/verified_smoke
MPLCONFIGDIR=/tmp/robot-mpl XDG_CACHE_HOME=/tmp/robot-cache .venv/bin/python evaluate.py --model docs/validation/smoke_checkpoint.zip --episodes 5 --seed 1000 --output docs/validation/nominal
MPLCONFIGDIR=/tmp/robot-mpl XDG_CACHE_HOME=/tmp/robot-cache .venv/bin/python evaluate.py --model docs/validation/smoke_checkpoint.zip --episodes 5 --seed 1000 --randomize --output docs/validation/randomized
MUJOCO_GL=egl .venv/bin/python evaluate.py --model docs/validation/smoke_checkpoint.zip --episodes 1 --seed 1000 --video --output runs/verified_video
.venv/bin/python train.py --resume docs/validation/smoke_checkpoint.zip --steps 1024 --seed 0 --output runs/resume_check
```

Training saved a 10,000-step checkpoint and a 10,240-step final model. The supplied `smoke_checkpoint.zip` is the **10,000-step checkpoint**, not the final model. Checkpoint reload and separate resumed 1,024-step training completed; resumed training is a software check, not an improved walking result. TensorBoard events and best/checkpoint saves were produced under `runs/verified_smoke`. Runs are ignored by Git; the evidence checkpoint, source training configuration, CSVs and video are retained under `docs/validation`.

The original training configuration predates the added source-hash reporting and stricter support/clearance metric. Neither changed actuator physics, observations or reward. Fixed-seed evaluations were rerun using the final evaluation code and are stored below. `manifest.json` hashes the delivered sources and records installed versions. Code/test passing does not establish policy quality.

## Observed policy results

The nominal-trained checkpoint was evaluated with deterministic actions on seeds **1000–1004**, separately with and without randomization. These are five episodes per condition, not enough to establish a robust failure probability. Fall rate is observed **0/5** in each condition.

| Metric | Nominal | Randomized |
|---|---:|---:|
| Mean distance | 0.0015243347 m | 0.0019358407 m |
| Mean forward speed | 0.0000508112 m/s | 0.0000645280 m/s |
| Duration per episode | 30 s | 30 s |
| Falls | 0/5 | 0/5 |
| Mean total reward | 6.00596345 | 6.00868410 |
| Qualifying lifted steps / alternations | 0 / 0 | 0 / 0 |
| Walking successes | 0/5 | 0/5 |

The achieved result is **simulation standing with slight drift**, not stable forward walking. The target of at least 0.3 m with alternating lifted steps in 30 s is unmet. Real standing/walking/transfer remain entirely unmeasured.

- [Nominal CSV](validation/nominal/episodes.csv) and [summary](validation/nominal/summary.json)
- [Randomized CSV](validation/randomized/episodes.csv) and [summary](validation/randomized/summary.json)
- [30 s visualization](validation/nominal.mp4), [inspected preview](validation/model_preview.png)
- [Saved policy checkpoint](validation/smoke_checkpoint.zip)
- [Torque calculations](validation/torque_estimates.json)
- [Finite CAD intersection report](validation/clearances.json)
- [Source/version manifest](validation/manifest.json)

## Mechanical/numerical boundaries

The explicit mass ledger totals **0.2084311334 kg**, with six servo masses assigned once. CAD has seven connected watertight frame meshes plus two sole boxes. The mesh audit checks home, zero, all low, all high, one swing and 50 random poses (seed 123): **55 poses** have no checked frame/frame or frame/assigned-servo-case intersection. Unmeasured ears, horns, screw access, all neighboring cases/boards/wires, continuous swept paths and structural strength are not certified by this finite audit.

No package accessory, shaft/ear/horn dimension, current, continuous torque, motor lifetime, power connector rating or frame manufacturing fit has been physically confirmed. The approved design gate remains outstanding. The twin and print files explicitly retain provisional status until those measurements and the delivered budget pass.

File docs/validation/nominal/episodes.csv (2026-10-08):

distance_m | lateral_distance_m | duration_s | mean_speed_m_s | fallen | total_reward | lifted_steps_left | lifted_steps_right | alternations | walking_success | domain_randomization | episode | seed | terminated | truncated
0.0018179604228832492 | -0.003101172894729066 | 30.0 | 6.059868076277497e-05 | False | 6.00900676832695 | 0 | 0 | 0 | False | False | 0 | 1000 | False | True
0.0012807568489724467 | -0.003358231734815522 | 30.0 | 4.269189496574822e-05 | False | 6.004267159904958 | 0 | 0 | 0 | False | False | 1 | 1001 | False | True
0.0014794025313516169 | -0.0036126761747640457 | 30.0 | 4.931341771172056e-05 | False | 6.0052272004321186 | 0 | 0 | 0 | False | False | 2 | 1002 | False | True
0.0017750409601798847 | -0.003445606904423324 | 30.0 | 5.9168032005996154e-05 | False | 6.0077660015502135 | 0 | 0 | 0 | False | False | 3 | 1003 | False | True
0.0012685127159659981 | -0.003808470840503631 | 30.0 | 4.2283757198866604e-05 | False | 6.0035501365075365 | 0 | 0 | 0 | False | False | 4 | 1004 | False | True

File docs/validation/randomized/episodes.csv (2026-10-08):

distance_m | lateral_distance_m | duration_s | mean_speed_m_s | fallen | total_reward | lifted_steps_left | lifted_steps_right | alternations | walking_success | domain_randomization | episode | seed | terminated | truncated
0.00236834114276996 | -0.0024115449162673643 | 30.0 | 7.894470475899866e-05 | False | 6.011580486592631 | 0 | 0 | 0 | False | True | 0 | 1000 | False | True
0.002495401523110506 | -0.0027071491932173356 | 30.0 | 8.318005077035019e-05 | False | 6.016325054972735 | 0 | 0 | 0 | False | True | 1 | 1001 | False | True
0.0016139497918442746 | -0.003854876227008346 | 30.0 | 5.379832639480915e-05 | False | 6.002222638896414 | 0 | 0 | 0 | False | True | 2 | 1002 | False | True
0.003507784767278795 | -0.001124857474573404 | 30.0 | 0.00011692615890929317 | False | 6.024818609799643 | 0 | 0 | 0 | False | True | 3 | 1003 | False | True
-0.0003062739210979089 | -0.005558000002357542 | 30.0 | -1.020913070326363e-05 | False | 5.988473731684045 | 0 | 0 | 0 | False | True | 4 | 1004 | False | True

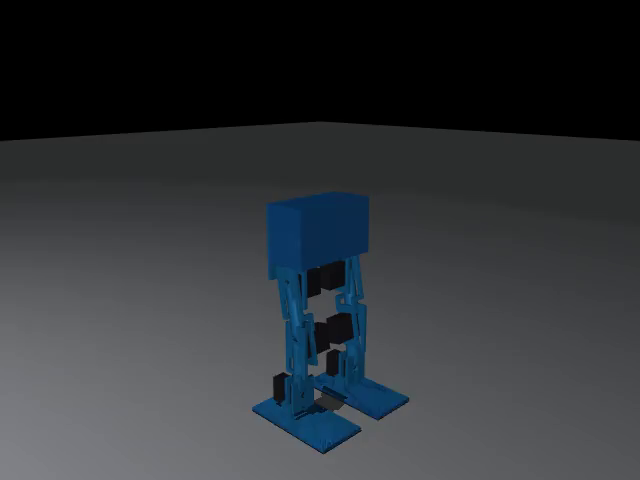
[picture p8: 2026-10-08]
docs/validation/model_preview.png

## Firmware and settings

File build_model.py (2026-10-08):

"""Generate MJCF and body mass/COM/inertia table from physical_spec.json.

Frames use solid-CAD inertia; other components use uniform-box estimates.
Aggregate with the parallel-axis theorem. None are measured hardware inertias.
Model remains provisional until hardware gates pass.
"""
import copy
import json
from pathlib import Path
import xml.etree.ElementTree as ET
import numpy as np
from robot_config import ROOT, HOME, SERVO_KP, SERVO_KV, SERVO_TORQUE, PHYSICS_DT


def physical_bodies(spec):
    bodies = copy.deepcopy(spec["bodies"])
    lookup = {body["name"]: body for body in bodies}
    for body in bodies:
        if "mirror_of" in body:
            body["components"] = copy.deepcopy(lookup[body["mirror_of"]]["components"])
            for comp in body["components"]:
                comp["name"] = comp["name"].replace("left_", "right_")
                comp["com"][1] *= -1
                if "inertia_tensor" in comp:
                    mirror = np.diag([1, -1, 1])
                    comp["inertia_tensor"] = (mirror @ np.array(comp["inertia_tensor"]) @ mirror).tolist()
    return bodies


def aggregate(components):
    mass = sum(c["mass"] for c in components)
    com = sum(c["mass"] * np.array(c["com"]) for c in components) / mass
    inertia = np.zeros((3, 3))
    for c in components:
        m = c["mass"]
        x, y, z = c["dimensions"]
        inertia += np.array(c.get("inertia_tensor", np.diag([m * (y*y + z*z) / 12, m * (x*x + z*z) / 12, m * (x*x + y*y) / 12])))
        d = np.array(c["com"]) - com
        inertia += m * (np.dot(d, d) * np.eye(3) - np.outer(d, d))
    return mass, com, inertia


def fmt(values):
    return " ".join(f"{x:.10g}" for x in np.atleast_1d(values))


def generate(output=ROOT / "robot.xml"):
    spec = json.loads((ROOT / "physical_spec.json").read_text())
    bodies = physical_bodies(spec)
    root = ET.Element("mujoco", model="SchoolBipedS6_provisional")
    ET.SubElement(root, "compiler", angle="radian", autolimits="true", inertiafromgeom="false")
    ET.SubElement(root, "option", timestep=str(PHYSICS_DT), gravity="0 0 -9.81", integrator="implicitfast", iterations="60")
    visual = ET.SubElement(root, "visual")
    ET.SubElement(visual, "global", offwidth="960", offheight="720")
    ET.SubElement(visual, "map", znear="0.002")
    default = ET.SubElement(root, "default")
    ET.SubElement(default, "joint", limited="true", damping="0.002", armature="0.000005", frictionloss="0.001")
    ET.SubElement(default, "geom", condim="3", friction="0.8 0.005 0.0001", solref="0.008 1", solimp="0.9 0.95 0.001")
    ET.SubElement(default, "position", kp=str(SERVO_KP), kv=str(SERVO_KV), forcelimited="true", forcerange=fmt([-SERVO_TORQUE, SERVO_TORQUE]), ctrllimited="true")
    asset = ET.SubElement(root, "asset")
    for b in bodies:
        ET.SubElement(asset, "mesh", name=b["name"] + "_mesh", file="cad/stl/" + b["name"] + ".stl", scale="0.001 0.001 0.001")
    world = ET.SubElement(root, "worldbody")
    ET.SubElement(world, "light", pos="0 -1 2", dir="0 0 -1", diffuse="0.8 0.8 0.8")
    ET.SubElement(world, "geom", name="floor", type="plane", size="3 3 0.05", rgba="0.87 0.88 0.90 1")
    elems = {"world": world}
    table = []
    for b in bodies:
        elem = ET.SubElement(elems[b["parent"]], "body", name=b["name"], pos=fmt(b["position"]))
        elems[b["name"]] = elem
        ET.SubElement(elem, "geom", name=b["name"] + "_visual", type="mesh", mesh=b["name"] + "_mesh", contype="0", conaffinity="0", group="2", rgba="0.12 0.55 0.83 1")
        mass, com, tensor = aggregate(b["components"])
        full = [tensor[0, 0], tensor[1, 1], tensor[2, 2], tensor[0, 1], tensor[0, 2], tensor[1, 2]]
        ET.SubElement(elem, "inertial", mass=fmt(mass), pos=fmt(com), fullinertia=fmt(full))
        table.append({"body": b["name"], "mass_kg": mass, "com_m": com.tolist(), "fullinertia_kg_m2": full, "components": b["components"]})
        if b["name"] == "torso":
            ET.SubElement(elem, "freejoint", name="root")
            ET.SubElement(elem, "geom", name="torso_collision", type="box", pos="0 0 0.01", size="0.02 0.041 0.025", rgba="0.10 0.45 0.8 0.8")
            imu = next(c for c in b["components"] if c["name"] == "imu")
            ET.SubElement(elem, "site", name="imu_site", pos=fmt(imu["com"]), size="0.003", rgba="1 0.7 0 1")
            ET.SubElement(elem, "camera", name="overview", pos="0.42 -0.5 0.24", xyaxes="0.766 0.643 0 -0.26 0.31 0.916")
        else:
            ET.SubElement(elem, "joint", name=b["joint"], type="hinge", axis=fmt(b["axis"]), range=fmt(np.deg2rad(b["limits_deg"])))
            if b["name"].endswith("foot"):
                ET.SubElement(elem, "geom", name=b["name"] + "_plate", type="box", pos=fmt(spec["geometry"]["foot_center"]), size=fmt(np.array(spec["geometry"]["foot_dimensions"]) / 2), rgba="0.08 0.36 0.65 1")
                solepos = np.array(spec["geometry"]["foot_center"]); solepos[2] -= 0.002
                ET.SubElement(elem, "geom", name=b["name"] + "_sole", type="box", pos=fmt(solepos), size="0.045 0.0225 0.0005", rgba="0.15 0.15 0.15 1")
                ET.SubElement(elem, "site", name=b["name"] + "_sole_center", pos=fmt(solepos + [0, 0, -0.0005]), size="0.001")
            else:
                # Envelope of thin printed yoke, deliberately narrow for simple contacts.
                ET.SubElement(elem, "geom", name=b["name"] + "_link", type="capsule", fromto="0 0 -0.006 0 0 -0.044", size="0.006", rgba="0.12 0.55 0.83 1")
        for c in b["components"]:
            if "servo" in c["name"]:
                ET.SubElement(elem, "geom", name=c["name"] + "_case", type="box", pos=fmt(c["com"]), size=fmt(np.array(c["dimensions"]) / 2), rgba="0.15 0.15 0.17 1")
    act = ET.SubElement(root, "actuator")
    for b in bodies[1:]:
        ET.SubElement(act, "position", name=b["joint"] + "_servo", joint=b["joint"], ctrlrange=fmt(np.deg2rad(b["limits_deg"])))
    sensors = ET.SubElement(root, "sensor")
    ET.SubElement(sensors, "gyro", name="imu_gyro", site="imu_site")
    ET.SubElement(sensors, "accelerometer", name="imu_accel", site="imu_site")
    # Freejoint then L hip/knee/ankle then R hip/knee/ankle follows tree order.
    keys = ET.SubElement(root, "keyframe")
    ET.SubElement(keys, "key", name="home", qpos=fmt([0, 0, bodies[0]["position"][2], 1, 0, 0, 0, *HOME]), ctrl=fmt(HOME))
    ET.indent(root)
    ET.ElementTree(root).write(output, encoding="unicode", xml_declaration=False)
    Path(output).write_text('<!-- Generated from physical_spec.json; provisional hardware model. -->\n' + Path(output).read_text() + '\n')
    (ROOT / "docs").mkdir(exist_ok=True)
    (ROOT / "docs" / "mass_properties.json").write_text(json.dumps({"total_mass_kg": sum(b["mass_kg"] for b in table), "bodies": table}, indent=2) + "\n")
    return table


if __name__ == "__main__":
    table = generate()
    print(f"Generated robot.xml: {sum(b['mass_kg'] for b in table):.4f} kg, six servos")

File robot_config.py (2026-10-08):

"""Shared, conservative starting values. Units: SI; all actuator values are estimates."""
from dataclasses import dataclass
from pathlib import Path
import json
import numpy as np

ROOT = Path(__file__).resolve().parent
JOINT_NAMES = ("left_hip", "left_knee", "left_ankle", "right_hip", "right_knee", "right_ankle")
PHYSICAL_SPEC = json.loads((ROOT / "physical_spec.json").read_text())
_joint_bodies = {b["joint"]: b for b in PHYSICAL_SPEC["bodies"] if b["joint"] != "root"}
JOINT_LOW = np.deg2rad([_joint_bodies[n]["limits_deg"][0] for n in JOINT_NAMES])
JOINT_HIGH = np.deg2rad([_joint_bodies[n]["limits_deg"][1] for n in JOINT_NAMES])
HOME = np.deg2rad(PHYSICAL_SPEC["home_joint_angles_deg"])
PHYSICS_DT = 0.002
CONTROL_DT = 0.02
IMU_DT = 0.005
HISTORY = 5
FRAME_SIZE = 18  # gravity(3), gyro(3), applied target(6), previous action(6)
SERVO_KP = 0.9
SERVO_KV = 0.012
SERVO_TORQUE = 0.08  # Nm, estimated intermittent operating envelope, NOT continuous rating
TARGET_SPEED = np.deg2rad(180.0)  # commanded trajectory limit, not actual shaft speed
SERVO_NO_LOAD_SPEED = np.deg2rad(60 / 0.11)  # seller claim at 4.8 V; measure at 5 V
SERVO_DEADBAND = np.deg2rad(0.5)  # simple hysteresis surrogate; not mechanical backlash
BASE_DELAY = 0.02
GYRO_NOISE = 0.006  # rad/s standard deviation
ACCEL_NOISE = 0.04  # m/s^2 standard deviation
MAX_EPISODE_SECONDS = 30.0


@dataclass(frozen=True)
class Randomization:
    """Uniform multiplicative ranges, except noise/bias/offset/delay in SI units."""
    mass: float = 0.05
    friction: float = 0.15
    strength: float = 0.15
    speed: float = 0.10
    damping: float = 0.20
    offset_rad: float = np.deg2rad(1.0)
    delay_seconds: tuple[float, float] = (0.02, 0.04)
    gyro_bias: float = 0.01
    accel_bias: float = 0.05
    sensor_noise_scale: tuple[float, float] = (0.8, 1.2)


DR = Randomization()


def action_to_target(action):
    action = np.asarray(action, dtype=np.float64)
    if action.shape != (6,) or not np.isfinite(action).all():
        raise ValueError("Action must contain six finite normalized joint targets")
    return JOINT_LOW + (np.clip(action, -1, 1) + 1) * 0.5 * (JOINT_HIGH - JOINT_LOW)


def target_to_action(target):
    return np.clip(2 * (np.asarray(target) - JOINT_LOW) / (JOINT_HIGH - JOINT_LOW) - 1, -1, 1)

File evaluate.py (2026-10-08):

"""Evaluate policy/neutral baseline, distinguish forward sliding from lifted steps."""
import argparse
import csv
import json
import time
from pathlib import Path
import numpy as np
from humanoid_env import HumanoidEnv
from robot_config import ROOT, HOME, CONTROL_DT, target_to_action


def evaluate(model_path=None, episodes=10, seed=1000, randomize=False,
             output=ROOT / "runs" / "evaluation", video=False, render=False,
             episode_seconds=30):
    output = Path(output)
    if episodes <= 0:
        raise ValueError("episodes must be positive")
    output.mkdir(parents=True, exist_ok=True)
    if video and render:
        raise ValueError("Choose video or human rendering, not both")
    mode = "rgb_array" if video else "human" if render else None
    env = HumanoidEnv(render_mode=mode, domain_randomization=randomize, episode_seconds=episode_seconds)
    model = None
    if model_path:
        from stable_baselines3 import PPO
        import torch
        torch.set_num_threads(1)
        model = PPO.load(model_path, device="cpu")
    records = []
    writer = None
    try:
        if video:
            import imageio.v2 as imageio
            writer = imageio.get_writer(output / "episode_0.mp4", fps=50, codec="libx264", macro_block_size=16)
        for episode in range(episodes):
            obs, info = env.reset(seed=seed + episode)
            terminated = truncated = False
            while not (terminated or truncated):
                started = time.monotonic()
                action = model.predict(obs, deterministic=True)[0] if model else target_to_action(HOME)
                obs, reward, terminated, truncated, info = env.step(action)
                if writer is not None and episode == 0:
                    writer.append_data(env.render())
                if render:
                    time.sleep(max(0, CONTROL_DT - (time.monotonic() - started)))
            row = {k: v for k, v in info.items() if k != "reward_terms"}
            row.update(episode=episode, seed=seed + episode, terminated=terminated, truncated=truncated)
            records.append(row)
            print(json.dumps(row))
        summary = {"episodes": episodes, "falls": sum(r["fallen"] for r in records),
                   "fall_rate": float(np.mean([r["fallen"] for r in records])),
                   "mean_distance_m": float(np.mean([r["distance_m"] for r in records])),
                   "mean_forward_speed_m_s": float(np.mean([r["mean_speed_m_s"] for r in records])),
                   "mean_duration_s": float(np.mean([r["duration_s"] for r in records])),
                   "mean_total_reward": float(np.mean([r["total_reward"] for r in records])),
                   "walking_successes": sum(r["walking_success"] for r in records),
                   "domain_randomization": randomize, "policy": str(model_path) if model_path else "neutral baseline"}
        import hashlib
        summary["xml_sha256"] = hashlib.sha256((ROOT / "robot.xml").read_bytes()).hexdigest()
        summary["seeds"] = list(range(seed, seed + episodes))
        with (output / "episodes.csv").open("w", newline="") as f:
            c = csv.DictWriter(f, fieldnames=list(records[0]))
            c.writeheader(); c.writerows(records)
        (output / "summary.json").write_text(json.dumps(summary, indent=2) + "\n")
        print(json.dumps(summary, indent=2))
        return summary
    finally:
        if writer is not None:
            writer.close()
        env.close()


def main():
    p = argparse.ArgumentParser(description=__doc__)
    p.add_argument("--model", type=Path)
    p.add_argument("--episodes", type=int, default=10)
    p.add_argument("--seed", type=int, default=1000)
    p.add_argument("--randomize", action="store_true")
    p.add_argument("--output", type=Path, default=ROOT / "runs" / "evaluation")
    p.add_argument("--episode-seconds", type=float, default=30)
    group = p.add_mutually_exclusive_group()
    group.add_argument("--video", action="store_true")
    group.add_argument("--render", action="store_true")
    args = p.parse_args()
    if args.episodes <= 0:
        p.error("--episodes must be positive")
    evaluate(args.model, args.episodes, args.seed, args.randomize, args.output,
             args.video, args.render, args.episode_seconds)


if __name__ == "__main__":
    main()

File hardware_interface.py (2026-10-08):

"""Bounded serial wire format and calibration helpers, with no automatic arming.

The MCU implementation is specified in docs/HARDWARE.md. No tested firmware or
live hardware deployment is claimed. All angles here are radians, wire values mrad.
"""
from dataclasses import dataclass
import binascii
import numpy as np
from robot_config import JOINT_LOW, JOINT_HIGH

MAX_FRAME_BYTES = 192
BAUD = 460800  # USB CDC value; sufficient for optional UART implementation too
WATCHDOG_SECONDS = 0.100


def encode_frame(fields):
    payload = ",".join(str(field) for field in fields).encode("ascii")
    crc = binascii.crc_hqx(payload, 0xFFFF)
    frame = payload + f"*{crc:04X}\n".encode("ascii")
    if len(frame) > MAX_FRAME_BYTES:
        raise ValueError("Frame exceeds bounded buffer")
    return frame


def decode_frame(frame):
    if not isinstance(frame, bytes) or len(frame) > MAX_FRAME_BYTES or not frame.endswith(b"\n"):
        raise ValueError("Invalid frame length/termination")
    payload, sep, checksum = frame[:-1].partition(b"*")
    if not sep or len(checksum) != 4:
        raise ValueError("Missing CRC16")
    if binascii.crc_hqx(payload, 0xFFFF) != int(checksum, 16):
        raise ValueError("CRC mismatch")
    fields = payload.decode("ascii").split(",")
    if len(fields) < 2 or fields[1] != "1":
        raise ValueError("Unsupported protocol version")
    return fields


def command_frame(sequence, timestamp_ms, angles):
    q = np.asarray(angles, dtype=float)
    if q.shape != (6,) or not np.isfinite(q).all():
        raise ValueError("Six finite radian targets required")
    if np.any(q < JOINT_LOW) or np.any(q > JOINT_HIGH):
        raise ValueError("Target exceeds joint-safe limits")
    if not 0 <= int(sequence) <= 65535 or not 0 <= int(timestamp_ms) <= 0xFFFFFFFF:
        raise ValueError("Sequence or timestamp out of wire range")
    # Round safe endpoints inward; 35° rounded to 611 mrad would exceed 35°.
    wire = np.clip(np.rint(q * 1000), np.ceil(JOINT_LOW * 1000), np.floor(JOINT_HIGH * 1000)).astype(int)
    return encode_frame(["C", 1, int(sequence), int(timestamp_ms), *wire])


@dataclass(frozen=True)
class Telemetry:
    sequence: int
    timestamp_ms: int
    status: int
    applied_targets: np.ndarray
    accelerometer: np.ndarray
    gyroscope: np.ndarray


def telemetry_frame(frame):
    fields = decode_frame(frame)
    if len(fields) != 17 or fields[0] != "T":
        raise ValueError("Expected T,version,sequence,time,status,6 targets,3 accel,3 gyro")
    values = [int(x) for x in fields[2:]]
    seq, ms, status = values[:3]
    if not (0 <= seq <= 65535 and 0 <= ms <= 0xFFFFFFFF and 0 <= status <= 31):
        raise ValueError("Invalid telemetry header")
    q = np.array(values[3:9], dtype=float) / 1000
    accel = np.array(values[9:12], dtype=float) / 1000
    gyro = np.array(values[12:15], dtype=float) / 1000
    # Quantization of endpoints is allowed, but arbitrary excursions are rejected.
    if np.any(q < JOINT_LOW - 0.001) or np.any(q > JOINT_HIGH + 0.001):
        raise ValueError("Invalid applied command range")
    if np.max(np.abs(accel)) > 16 * 9.81 + 0.01 or np.max(np.abs(gyro)) > np.deg2rad(2000) + 0.01:
        raise ValueError("IMU outside configured sensor ranges")
    return Telemetry(seq, ms, status, q, accel, gyro)


def calibrated_pulses(angles, zero_us, us_per_rad, direction, pulse_min, pulse_max):
    """Per-servo calibration; never infer a universal 0..180 degree PWM mapping."""
    arrays = [np.asarray(a, dtype=float) for a in (angles, zero_us, us_per_rad, direction, pulse_min, pulse_max)]
    if any(a.shape != (6,) or not np.isfinite(a).all() for a in arrays):
        raise ValueError("All calibration arrays must contain six finite values")
    q, zero, gain, sign, low, high = arrays
    if np.any(gain <= 0) or np.any(np.abs(sign) != 1) or np.any(low >= high):
        raise ValueError("Invalid calibration")
    if np.any(q < JOINT_LOW) or np.any(q > JOINT_HIGH):
        raise ValueError("Unsafe angle")
    pulses = zero + sign * gain * q
    if np.any(pulses < low) or np.any(pulses > high):
        raise ValueError("Calibration cannot represent requested angle safely")
    return np.rint(pulses).astype(int)

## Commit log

2026-10-08 Some basics
    [robot.xml]
2026-10-24 Implemented a scripted weight-handoff baseline: - Four qualifying alternating steps, advancing 6.6 cm in 30 seconds without falling. - Mirrored replay matches; 49 tests pass. - Randomized parameters 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
2026-10-24 Continued development and verification: - Fixed calibration-offset modelling; older policies are now rejected as incompatible. - Completed 29 sensitivity cases: nominal performance remains four scrip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
2026-10-26 Implemented the [servo-response review tools](/home/kolja/home/Code/robot/docs/RESPONSE_REVIEW.md): - Fit one trial and predict separate trials without refitting. - Export plots, residual CSVs, metri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
2026-10-27 Implemented and verified: - [Printable receiving and fit checklist](/home/kolja/home/Code/robot/docs/RECEIVING_CHECKLIST.md) - [Record template and offline reviewer instructions](/home/kolja/home/Cod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
2026-10-28 I’ve ordered everything!
